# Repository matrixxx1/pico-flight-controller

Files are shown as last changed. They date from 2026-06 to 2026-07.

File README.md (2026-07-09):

# Pico Flight Controller

Raspberry Pi Pico receiver and sensor testbed for a flight-controller-style build.

## Contents

- `main.py` - MicroPython firmware that reads the R8EF PPM signal on Pico `GP15` and drives the PCA9685 outputs through the HW-617 mux.
- `vl53l0x.py` - VL53L0X / UL53LDK distance sensor driver for the remaining side sensors.
- `ControllerTester/` - Vite + Three.js browser dashboard for Web Serial display of receiver and sensor readings.
- `simulator/` - Local browser simulator that generates Pico-shaped serial lines for drift, RC input, and fault testing.
- `QMC5883P.pdf` - Compass sensor reference sheet.
- `RPI_PICO-20260406-v1.28.0.uf2` - MicroPython UF2 used for Pico setup.

## Hardware Used

- Raspberry Pi Pico running MicroPython.
- Radiolink R8EF receiver, powered from the Pico `3V3` rail for bench testing.
- Radiolink transmitter bound to the R8EF.
- Radiolink Gens Ace 7.4V 2S LiPo battery powering the transmitter.
- HW-617 / TCA9548A I2C multiplexer.
- Three VL53L1X time-of-flight distance sensors for bottom, top, and front range sensing.
- Two UL53LDK / VL53L0X time-of-flight distance sensors for left/right side range sensing.
- GY-271 compass module with QMC5883P / HP5883 magnetometer.
- MPU-6050 accelerometer/gyroscope module.
- PCA9685 16-channel 12-bit I2C PWM servo driver.
- Four 60A ESCs for the main motors.
- Four X2807 1300KV brushless motors.
- FEICHAO 8A UBEC regulating the PCA9685 `V+` servo rail to 6V.
- MG995 55g metal-gear servo motors for mount/control-surface outputs.
- Four Hooyu RDS3225 25kg waterproof high-torque digital servos with full metal gears and dual shafts.
- MEUS Racing AUX RC light remote controller switch with LTVystore 5mm 5V prewired LED bulbs.
- Six Ovonic 1000mAh 6S 100C LiPo batteries with XT60 plugs.
- ISDT 60BAC 8A / 200W LiPo balance charger for the main 6S batteries.
- Radiolink CM210 charger for the transmitter battery.
- USB cable from the Pico to the Windows laptop.

## Battery Plan

Current battery inventory:

- `6x` Ovonic 1000mAh 6S 100C LiPo batteries with XT60 plugs.
- `1x` Radiolink Gens Ace 7.4V 2S LiPo battery for the transmitter.
- ISDT 60BAC 8A / 200W LiPo balance charger for the main 6S packs.
- Radiolink CM210 charger for the transmitter battery.

Intended battery assignment:

| Battery | Intended Load | Notes |
|---|---|---|
| 1 | Left front motor / ESC | 6S pack feeds the ESC motor power input. |
| 2 | Right front motor / ESC | 6S pack feeds the ESC motor power input. |
| 3 | Left rear motor / ESC | 6S pack feeds the ESC motor power input. |
| 4 | Right rear motor / ESC | 6S pack feeds the ESC motor power input. |
| 5 | Pico + receiver + HW-617 + sensors | Must go through a regulator/BEC before the Pico; do not connect 6S directly to Pico power pins. |
| 6 | FEICHAO 8A UBEC -> PCA9685 `V+` servo rail | 6S pack feeds the UBEC input; regulated 6V UBEC output feeds PCA9685 `V+`. |

Safety note: a 6S LiPo is `22.2V` nominal and `25.2V` fully charged. The Pico, HW-617, sensors, receiver, PCA9685 logic, and PCA9685 `V+` rail cannot take raw 6S voltage directly. The FEICHAO UBEC sits between the 6S pack and PCA9685 `V+` to cap that rail at 6V.

## Wiring Diagram

Current firmware reads the R8EF PPM stream on `GP15`, then sends flight-control output pulses to the PCA9685 on HW-617 channel 7.

```text
                       USB
Windows laptop <---------------- Raspberry Pi Pico
                                      |
                                      | GP15
                                      v
                              R8EF CH2 signal

Pico 3V3 --------------------+-------- R8EF VCC
                             +-------- HW-617 VCC
                             +-------- Sensor VCC/VIN rails

Pico GND --------------------+-------- R8EF GND
                             +-------- HW-617 GND
                             +-------- Sensor GND rails

Pico GP0 / SDA ---------------------- HW-617 SDA
Pico GP1 / SCL ---------------------- HW-617 SCL

Pico 3V3 ---------------------------- PCA9685 VCC
Pico GND ---------------------------- PCA9685 GND
FEICHAO 8A UBEC 6V OUT + ------------ PCA9685 V+
FEICHAO 8A UBEC GND ----------------- PCA9685 GND

HW-617 CH0: SC0/SCL + SD0/SDA ------- Bottom TOF0 / VL53L1X
HW-617 CH1: SC1/SCL + SD1/SDA ------- Top TOF1 / VL53L1X
HW-617 CH2: SC2/SCL + SD2/SDA ------- Right TOF2 / UL53LDK / VL53L0X
HW-617 CH3: SC3/SCL + SD3/SDA ------- Left TOF3 / UL53LDK / VL53L0X
HW-617 CH4: SC4/SCL + SD4/SDA ------- GY-271 compass
HW-617 CH5: SC5/SCL + SD5/SDA ------- MPU-6050 IMU
HW-617 CH6: SC6/SCL + SD6/SDA ------- Front TOF5 / VL53L1X
HW-617 CH7: SC7/SCL + SD7/SDA ------- PCA9685 PWM servo driver
```

## Wiring Table

| Device | Pin | Connects To | Notes |
|---|---|---|---|
| R8EF | CH2 signal | Pico `GP15` | PPM input for receiver-only firmware. |
| R8EF | VCC / middle pin | Pico `3V3` | The receiver is marked `3-15V`; `3V3` is for bench testing. |
| R8EF | GND / dark pin | Pico `GND` | Must share ground with the Pico. |
| HW-617 / TCA9548A | SDA | Pico `GP0` | Root I2C bus. |
| HW-617 / TCA9548A | SCL | Pico `GP1` | Root I2C bus. |
| HW-617 / TCA9548A | VCC | Pico `3V3` | Keep I2C logic at Pico-safe voltage. |
| HW-617 / TCA9548A | GND | Pico `GND` | Shared ground. |
| PCA9685 | SDA | HW-617 `SD7` | I2C data through mux channel 7. |
| PCA9685 | SCL | HW-617 `SC7` | I2C clock through mux channel 7. |
| PCA9685 | VCC | Pico `3V3` | Logic power; keeps I2C pullups Pico-safe. |
| PCA9685 | GND | Pico `GND` and FEICHAO UBEC GND | Common ground for logic and servo power. |
| PCA9685 | V+ | FEICHAO 8A UBEC regulated 6V output + | Servo/ESC power rail only; do not connect to Pico `3V3` or raw 6S. |
| ESC servo extension leads | Signal + GND only | PCA9685 `CH1`, `CH3`, `CH5`, `CH7` | Disconnect / remove the red wire from each ESC servo extension cable to prevent voltage backfeed into the PCA9685 rail. |
| MG995 55g metal-gear servos | Signal/V+/GND | PCA9685 servo outputs | Servo outputs are powered from the FEICHAO-regulated 6V `V+` rail. |
| Hooyu RDS3225 25kg servos | Signal/V+/GND | Available PCA9685 servo outputs | High-torque digital servos; confirm voltage/current draw before running several from the 8A UBEC at once. |
| Bottom TOF0 / VL53L1X | SDA/SCL | HW-617 `SD0` / `SC0` | Longer-range bottom/altitude distance sensor. |
| Top TOF1 / VL53L1X | SDA/SCL | HW-617 `SD1` / `SC1` | Longer-range top/ceiling distance sensor. |
| Right TOF2 / UL53LDK | SDA/SCL | HW-617 `SD2` / `SC2` | VL53L0X side distance sensor. |
| Left TOF3 / UL53LDK | SDA/SCL | HW-617 `SD3` / `SC3` | VL53L0X side distance sensor. |
| GY-271 | SDA/SCL | HW-617 `SD4` / `SC4` | Compass / magnetometer. |
| MPU-6050 | SDA/SCL | HW-617 `SD5` / `SC5` | Accelerometer/gyro IMU. |
| Front TOF5 / VL53L1X | SDA/SCL | HW-617 `SD6` / `SC6` | Longer-range front distance sensor, connected on mux channel 6. |
| PCA9685 | SDA/SCL | HW-617 `SD7` / `SC7` | PWM servo driver, connected on mux channel 7. |
| All I2C sensors | VCC / VIN | Pico `3V3` rail | Use 3.3V-compatible modules. |
| All I2C sensors | GND | Pico `GND` rail | Shared ground. |

The firmware uses the mux channel to choose the ToF driver because both VL53L0X and VL53L1X modules use the normal `0x29` I2C address. Channels `0`, `1`, and `6` are treated as VL53L1X. Channels `2` and `3` remain VL53L0X.

## PCA9685 Output Labels

The browser viewer labels the 16 PCA9685 outputs as `CH1` through `CH16`. Many PCA9685 boards are silk-screened `0` through `15`; if so, app `CH1` is the board's output `0`, app `CH2` is board output `1`, and so on.

ESC signal leads use servo extension cables into the PCA9685, but the red wire is disconnected/removed on each ESC extension. Only signal and ground are carried through the servo lead so the ESC/BEC side cannot backfeed voltage into the PCA9685 rail.

| App Channel | Output Label |
|---|---|
| CH1 | Left front ESC |
| CH2 | Left Front Mount MG995 servo |
| CH3 | Right front ESC |
| CH4 | Right front Mount MG995 servo |
| CH5 | Left Rear ESC |
| CH6 | Left Rear Mount MG995 servo |
| CH7 | Right Rear ESC |
| CH8 | Right Rear Mount MG995 servo |
| CH9 | Elevator MG995 servo |
| CH10 | Rudder MG995 servo |
| CH11 | Landing Gear MG995 servo |
| CH12 | MEUS Racing AUX RC light switch -> LTVystore 5mm 5V prewired LED bulbs |
| CH13 | Camera Pan MG995 servo |
| CH14 | Camera Tilt MG995 servo |
| CH15 | Spare |
| CH16 | Spare |

## Receiver Control Map

The receiver signal path is:

```text
R8EF CH2 PPM stream -> Pico GP15 -> HW-617 CH7 -> PCA9685 outputs
```

| RC Channel | Transmitter Control | PCA9685 Output |
|---|---|---|
| RC1 | Right stick left/right | Plane/transition rear mount aileron mix on CH6 and CH8; hover side-to-side ESC boost on CH1/CH5 or CH3/CH7, capped inside the 60% joystick ESC authority limit |
| RC2 | Right stick up/down / elevator | Plane elevator on CH9; transition elevator plus slight front ESC boost on CH1/CH3; hover pitch mix on front/rear ESCs and mounts with CH9 elevator centered |
| RC3 | Speed / throttle | CH1, CH3, CH5, CH7 ESC outputs, capped at 60% joystick authority |
| RC4 | Rudder stick | CH10 / board output 9 |
| RC5 | Flight mode / mount-position switch | Low = `flightmode1` / plane, mid = `flightmode2` / transition, high = `flightmode3` / hover |
| RC7 | Control mode switch | Low = RC mode and slow-blink lights; high = PID mode and fast-blink lights |
| RC8 | Trainer / PID gain | Scales throttle above idle, servo/mount travel, stick-driven ESC boosts, PID target bias, and PID correction output from 25% at low to 100% at high |

RC-derived ESC output is capped at `1600us`, which is 60% of the normal `1000us` to `2000us` ESC command range. The remaining 40% is reserved for the Pico's future PID stabilization output, not direct joystick authority. Servo and mount outputs use an expanded `500us` to `2500us` range so full receiver stick travel produces wider servo travel. RC8 acts as a trainer/PID gain: low maps to 25% authority and high maps to full 100% authority. The gain scales throttle above idle, servo deflection from center, mount travel from center, rear mount yaw/aileron mix, hover pitch mix, hover side-to-side ESC boost, PID target bias, and PID correction output; RC5 still selects the flight mode and RC7 selects RC/PID control mode. RC input values use a `6us` deadband to reduce servo jitter from tiny receiver pulse noise. RC5 maps the switch positions to calibrated mount postures: low/plane sends `1580us`, middle/transition sends `1915us`, and high/hover sends `2250us` before RC8 gain scaling. The rear motors are physically set opposite the front motors, so the same mode pulse creates the opposite front/rear posture.

In `flightmode1`, RC2 controls the elevator servo on CH9, RC4 controls the rudder servo, and RC1 controls the rear engine mounts differentially like ailerons. In `flightmode2`, RC2 still controls the elevator and also slightly boosts the front ESCs on CH1 and CH3; RC4 controls the rudder servo and both RC1 and RC4 contribute to rear mount aileron movement on CH6 and CH8. In `flightmode3`, CH9 elevator and CH10 rudder stay centered, RC4 controls rear mount yaw tilt, RC1 commands side-to-side hover movement by slightly increasing the opposing-side ESC pair, and RC2 commands hover pitch: stick up boosts the rear ESCs on CH5 and CH7 while nudging the rear mounts upward, and stick back boosts the front ESCs on CH1 and CH3 while slightly lowering the front mounts. If the receiver signal is missing, ESC outputs go to `1000us`, servos center at `1500us`, RC/PID mode falls back to RC mode, and the flight mode falls back to `flightmode1`.

In RC mode, the remote behaves as the direct command source. In PID mode, the Pico captures the current sensor state when RC7 goes high, then treats remote stick movement as a target-direction bias instead of a replacement for stabilization. Hover mode tries to hold the current world state using level pitch/roll, heading, and bottom-ToF altitude when available; stick commands bias that hold and keep the hover feedforward mixes active, so stick-right still slightly boosts the left front/rear ESCs while PID stabilizes around that movement. Plane mode holds the captured trajectory through attitude and heading corrections while stick commands bias the commanded trajectory. Transition mode blends hover and flight behavior with half-strength corrections. The current sensor stack does not provide GPS or optical-flow X/Y position, so PID mode cannot truly lock horizontal X/Y world position yet; it can only stabilize attitude, heading, and altitude while applying directional movement commands.

The light controller is now driven by mode-change pulses on CH12 instead of direct RC7 passthrough. The controller starts solid when powered; one off/on pulse selects the slow blink pattern, a second off/on pulse selects fast blink, and a third cycles back to solid. RC mode targets slow blink. PID mode targets fast blink.

Rear mount aileron movement is limited before mixing into CH6 and CH8 so roll inputs do not swing the rear motor mounts through their full mechanical range. Plane mode uses 50% rear aileron authority, and transition mode uses 25% rear aileron authority.

In transition and hover, rear mount yaw is capped at the flight-mode mount setting, so turning inputs can pull a rear mount toward flight position but not past it. In transition mode, rudder/yaw input is not added to the aileron differential mix: left rudder pulls the right rear mount toward flight position, and right rudder pulls the left rear mount toward flight position.

Sensor telemetry is lightly smoothed in firmware for steadier display while sitting still. RC channel values are not smoothed before control output, so stick/switch response stays direct.

## R8EF Mode

```text
R8EF CH2 signal -> Pico GP15
R8EF VCC        -> Pico 3V3
R8EF GND        -> Pico GND
```

The R8EF needs SBUS/PPM mode for CH2 to output a combined PPM stream.

- Red LED: PWM mode, each channel is a separate PWM output.
- Blue/purple LED: SBUS/PPM mode, where `CH1` is SBUS and `CH2` is PPM.
- Toggle mode by quick-pressing the receiver `ID SET` button twice within 1 second.

## Browser Viewer

```powershell
cd ControllerTester
npm install
npm run dev -- --port 5173
```

Then open `http://127.0.0.1:5173` in Chrome or Edge and connect to the Pico over Web Serial.

## Simulator

```powershell
cd simulator
.\Start-Simulator.ps1
```

Then open the URL printed by the launcher, starting with `http://127.0.0.1:5174`. The simulator can copy generated serial lines into the `ControllerTester` raw/manual parser, run short RC instruction scripts, read a USB transmitter/game-controller through the browser Gamepad API, and read CH340-style serial adapters through Web Serial.

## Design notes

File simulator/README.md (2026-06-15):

# Pico Setup Simulator

This is a local browser simulator for the Pico flight-controller test setup.

It emits the same one-line text shape as `main.py`, for example:

```text
sensor=QMC5883P / HP5883 x=420 y=0 z=0 xuT=0.42 yuT=0.00 zuT=0.00 heading=0.0 tof0=620 tof1=680 tof2=760 tof3=760 tof6=900 adxl=ok ax=0.000 ay=0.000 az=1.000 pitch=0.0 roll=0.0 rc=ppm rc1=1500 rc2=1500 rc3=1500 rc4=1500 rc5=1000 rc6=1500 rc7=1000 rc8=1500
```

Use it to test:

- Wind drift scenarios.
- RC instruction sequences.
- Low-altitude approach behavior.
- TOF, compass, and stale RC failure modes.
- Manual parser testing in `ControllerTester` by copying the generated serial line.
- USB transmitter/game-controller input through the browser Gamepad API.
- USB serial adapters such as CH340 on `COM4` through Web Serial.

## Launch

From PowerShell:

```powershell
.\Start-Simulator.ps1
```

Or double-click:

```text
Start-Simulator.bat
```

The launcher starts at `http://127.0.0.1:5174`. If that port is busy, it picks the next free port and prints the exact URL.

## USB Transmitter Control

Plug in the transmitter, open the simulator from localhost, then click `Use T8FB`.

Browsers only expose gamepads after user interaction. If the status stays on waiting, move a stick, press a transmitter button, or unplug/replug the USB cable while the simulator is open.

Default mapping:

- Axis 0 -> `rc1` yaw.
- Axis 1 -> `rc2` pitch, inverted.
- Axis 2 -> `rc3` throttle, inverted.
- Axis 3 -> `rc4` roll.

The live USB status shows the raw axes and mapped `rc1..rc4` values so the mapping can be adjusted once we see what the T8FB reports on this laptop.

## Serial Adapter Control

If the transmitter cable appears as `USB-SERIAL CH340 (COM4)`, click `Connect COM4` in the simulator and choose that port from the browser picker.

The simulator tries these input shapes:

- Text lines containing `rc1=... rc2=...`.
- Text lines containing at least four PWM-like values from `900` to `2250`.
- FlySky-style iBUS binary frames.
- SBUS binary frames when baud is set to `100000 SBUS 8E2`.

Start with `115200`. If the status only shows changing raw hex bytes and no channel mapping, try `9600`, `57600`, and `100000 SBUS 8E2`.

## Instruction Script

The script box accepts one instruction per line. Values are receiver PWM microseconds unless noted.

```text
scenario=manual throttle=1550 yaw=1500 pitch=1450 roll=1500 wind=0 hold=1.0
scenario=manual throttle=1580 yaw=1500 pitch=1500 roll=1850 wind=45 hold=1.4
scenario=fault tof=err mag=err rc=stale hold=1.0
```

Useful fields:

- `scenario`: `manual`, `drift`, `rc`, `fault`, or `landing`.
- `throttle`: maps to `rc3`.
- `yaw` or `ch1`: maps to `rc1`.
- `pitch` or `ch2`: maps to `rc2`.
- `roll` or `ch4`: maps to `rc4`.
- `wind`: `-100` to `100`, used for drift.
- `hold`: seconds to hold the instruction.
- `tof=err`, `mag=err`, `rc=stale`: simulate fault modes.

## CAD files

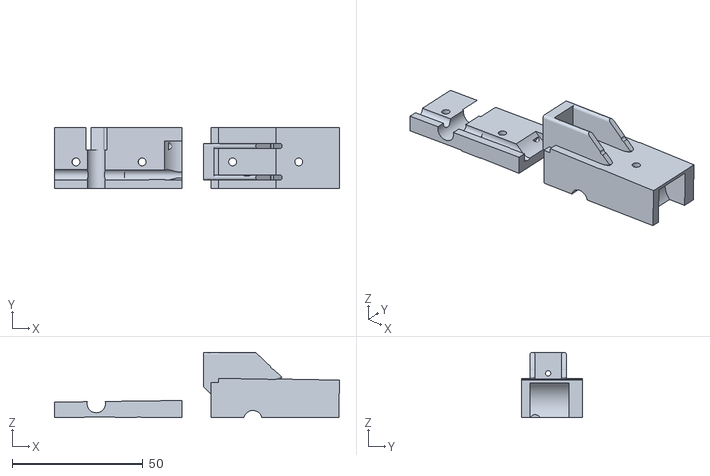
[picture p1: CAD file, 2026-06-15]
3dmodels/Landing_gear_front.stl
108.8 x 23.1 x 24.9

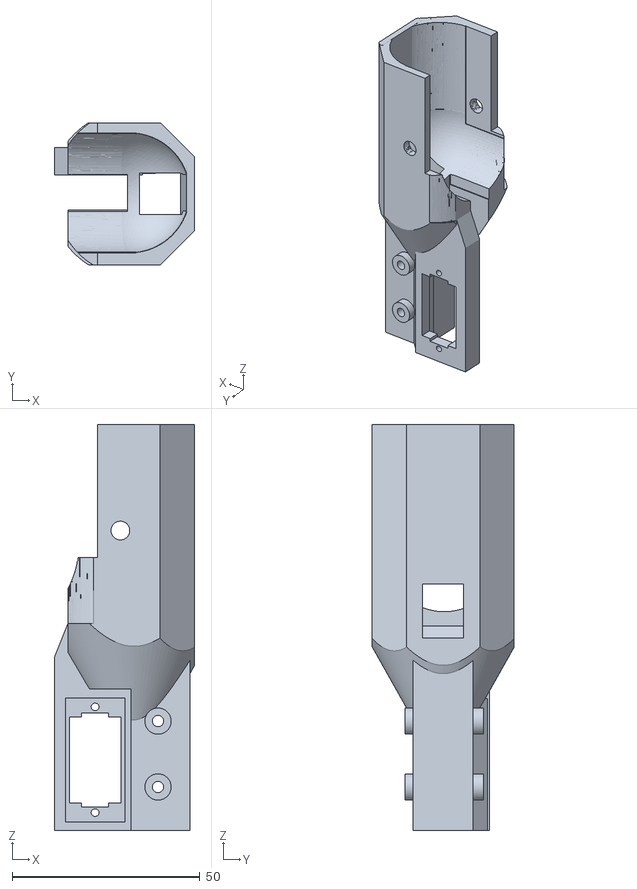
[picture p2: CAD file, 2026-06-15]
3dmodels/Wing_to_EngineMount.stl
37.5 x 38.0 x 108.3

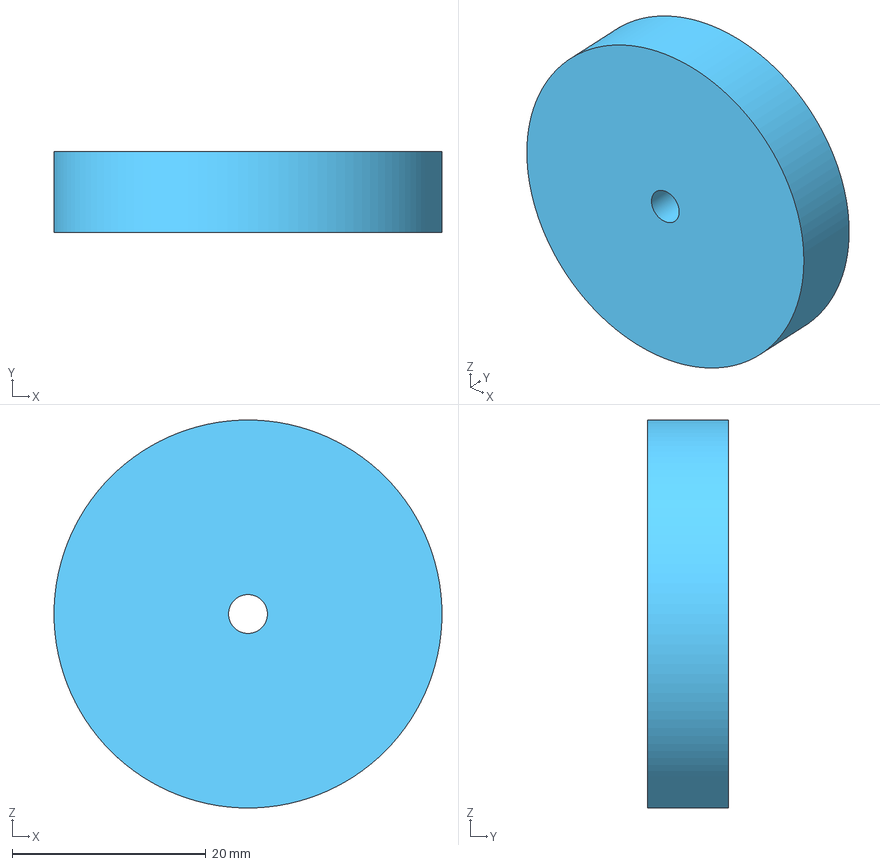
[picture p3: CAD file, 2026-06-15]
3dmodels/Landing_gear_Wheel.3mf
40.0 x 8.37 x 40.0 mm

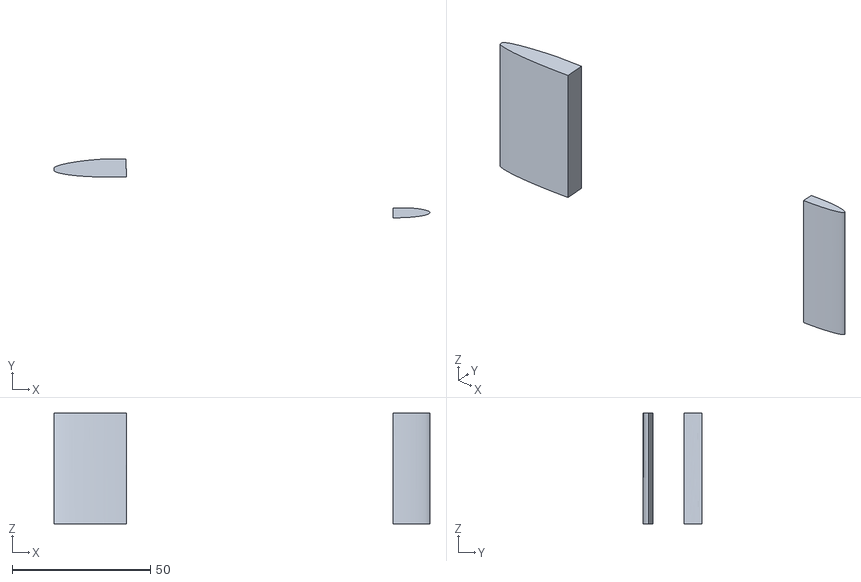
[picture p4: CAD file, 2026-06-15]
3dmodels/Wing_clips.stl
135.9 x 21.2 x 40.0

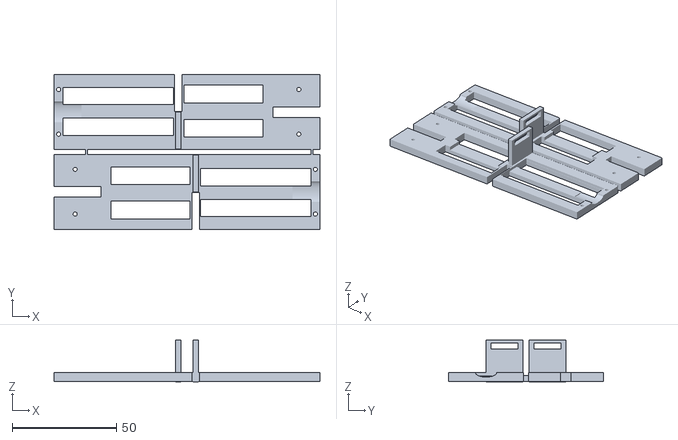
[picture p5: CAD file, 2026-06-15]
3dmodels/pico multiplexor.stl
127.9 x 74.4 x 20.0

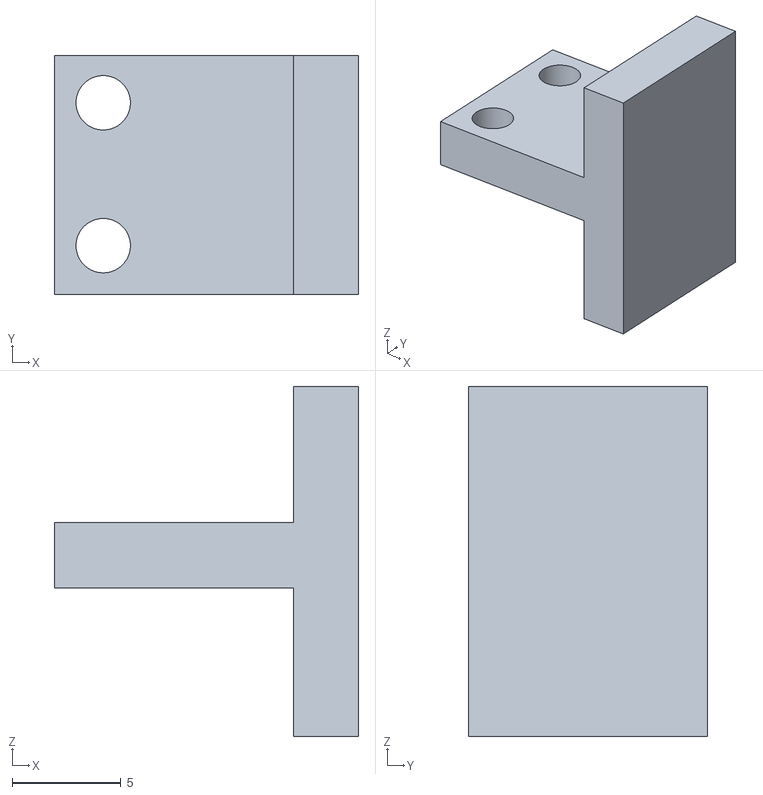
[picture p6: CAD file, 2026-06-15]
3dmodels/vl53LDK.stl
14.0 x 11.0 x 16.1

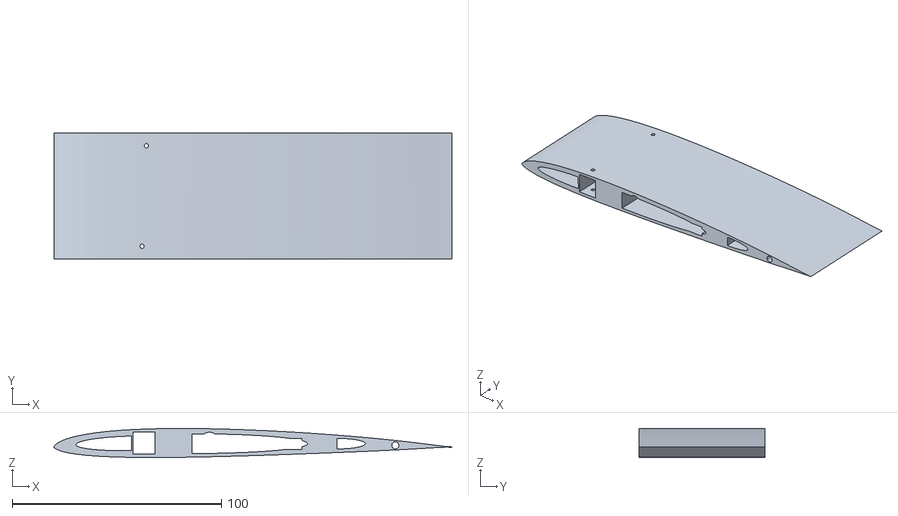
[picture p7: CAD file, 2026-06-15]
3dmodels/shortwings.stl
190.0 x 60.0 x 13.9

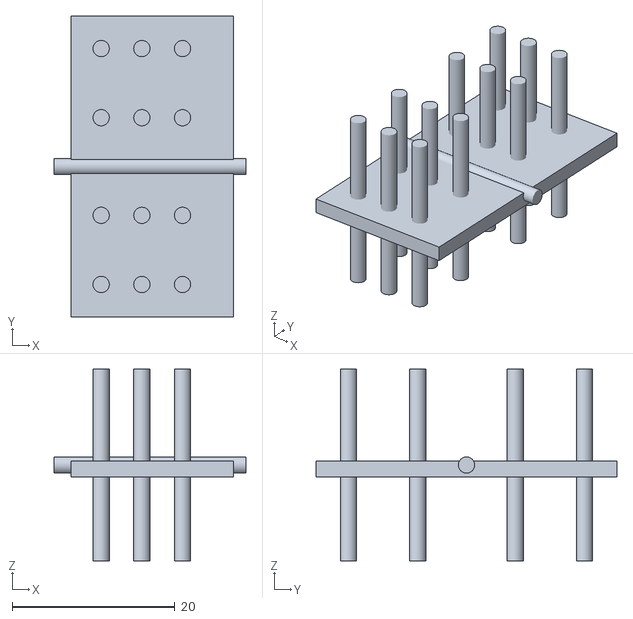
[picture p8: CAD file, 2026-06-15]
3dmodels/hinge.stl
23.6 x 37.0 x 23.6

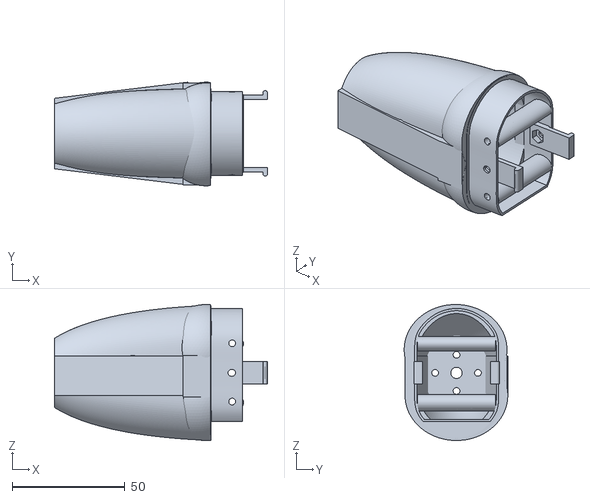
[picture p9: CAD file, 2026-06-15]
3dmodels/Cowl.stl
94.5 x 46.0 x 60.3

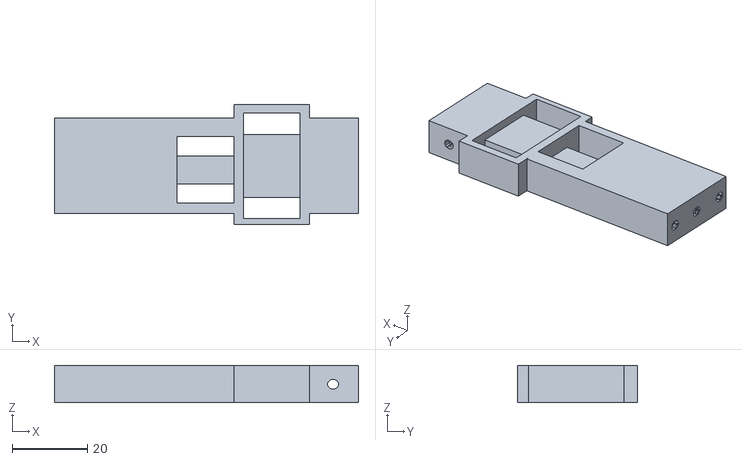
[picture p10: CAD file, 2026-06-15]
3dmodels/Cowl-gyro-plate.stl
80.7 x 31.9 x 9.84

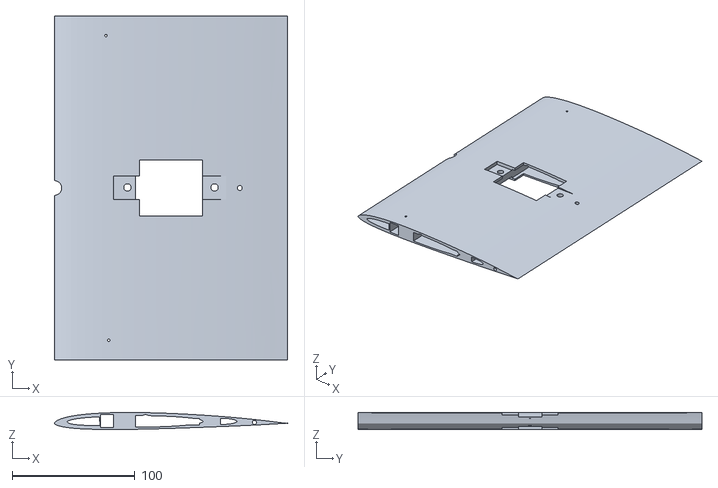
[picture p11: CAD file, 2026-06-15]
3dmodels/Wing_central.stl
190.0 x 280.0 x 13.9

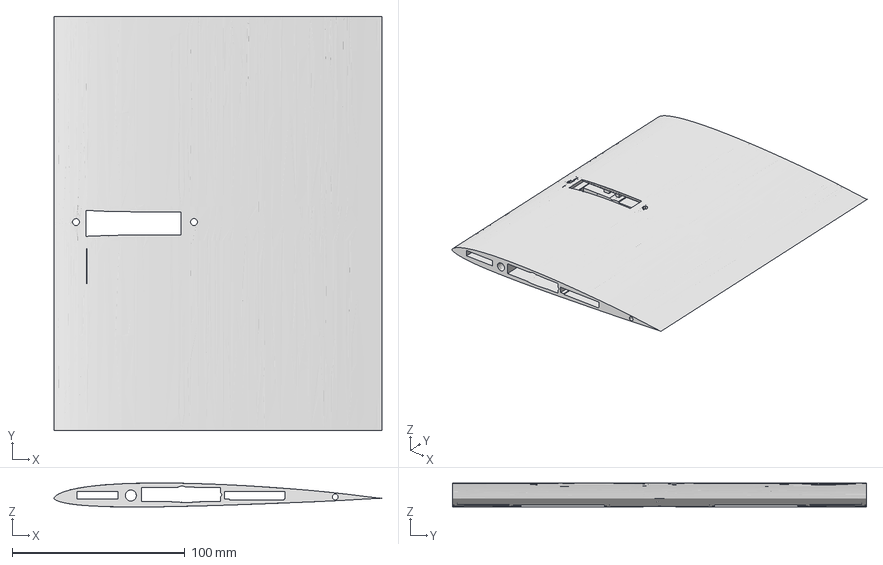
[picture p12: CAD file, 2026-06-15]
3dmodels/Wing_engineMount.3mf
190.0 x 239.9 x 13.8 mm

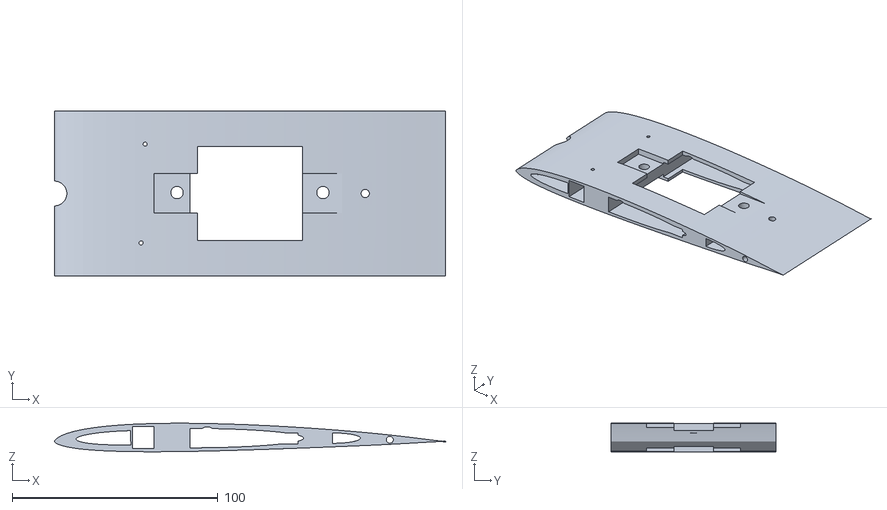
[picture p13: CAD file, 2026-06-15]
3dmodels/short-wing-with-mountl.stl
190.0 x 80.0 x 13.9

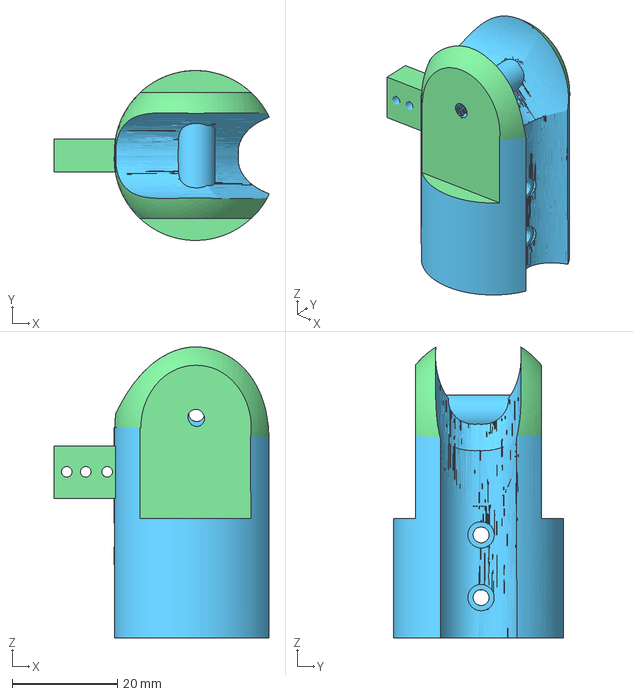
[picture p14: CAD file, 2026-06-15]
3dmodels/EngineMount -Outer.3mf
40.9 x 32.3 x 55.3 mm

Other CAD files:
3dmodels/EngineMount-Inner.stl
3dmodels/NoseCone.stl
3dmodels/rudder.stl
3dmodels/Wing_to_EngineMount-MG995-servo.stl
3dmodels/Elevon.recreated-clean.stl
3dmodels/rear-wheel-mount.stl

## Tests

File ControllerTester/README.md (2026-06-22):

# Pico Controller Tester

Use `Start-ControllerTester.bat` to launch the app.

Do not open `index.html` directly. The app uses browser modules and Web Serial, so it needs to run from `http://127.0.0.1:5173`.

## Pico I2C wiring

Pico shared I2C bus:

```text
Pico 3V3(OUT) -> HW-617 VCC
Pico GND      -> HW-617 GND
Pico GP1      -> HW-617 SCL
Pico GP0      -> HW-617 SDA
```

Sensors through the HW-617:

```text
HW-617 SC0/SD0 -> Bottom TOF0 / VL53L1X SCL/SDA
HW-617 SC1/SD1 -> Top TOF1 / VL53L1X SCL/SDA
HW-617 SC2/SD2 -> Right TOF2 / VL53L0X SCL/SDA
HW-617 SC3/SD3 -> Left TOF3 / VL53L0X SCL/SDA
HW-617 SC4/SD4 -> GY-271 SCL/SDA
HW-617 SC5/SD5 -> MPU-6050 SCL/SDA
HW-617 SC6/SD6 -> Front TOF5 / VL53L1X SCL/SDA
HW-617 SC7/SD7 -> PCA9685 SCL/SDA

HW-617 3V3/GND -> each ToF sensor VIN/GND
HW-617 3V3/GND -> GY-271 VCC/GND
HW-617 3V3/GND -> MPU-6050 VCC/GND
Pico 3V3/GND    -> PCA9685 VCC/GND
External BEC +  -> PCA9685 V+
External BEC GND -> PCA9685 GND
```

The Pico code expects the HW-617/TCA9548A at `0x70`, VL53L1X sensors at normal `0x29` on channels `0`, `1`, and `6`, VL53L0X sensors at normal `0x29` on channels `2` and `3`, the GY-271 on channel `4`, the MPU-6050 at `0x68` or `0x69` on channel `5`, and the PCA9685 at its normal `0x40` address on channel `7`.

## Flight modes

The viewer shows the active flight mode from the Pico serial stream. RC5 low is `flightmode1` / plane mode, RC5 middle is `flightmode2` / transition mode, and RC5 high is `flightmode3` / hover mode. In plane mode, RC4 controls the rudder servo. In transition mode, RC4 controls both the rudder servo and rear mount yaw tilt. In hover mode, RC4 tilts the rear mount pair for yaw while the rudder servo centers.

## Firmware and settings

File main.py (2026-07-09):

from machine import I2C, Pin, disable_irq, enable_irq
from time import sleep, ticks_diff, ticks_us
import math

try:
    from vl53l0x import VL53L0X
except ImportError:
    VL53L0X = None


I2C_BUS = 0
SDA_PIN = 0
SCL_PIN = 1
FREQ = 100_000

QMC5883L_ADDR = 0x0D
HMC5883L_ADDR = 0x1E
QMC5883P_ADDR = 0x2C
QMC5883P_ALT_ADDR = 0x0C
TCA9548A_ADDR = 0x70
PCA9685_ADDR = 0x40
VL53L0X_ADDR = 0x29
ADXL345_ADDR = 0x53
MPU6050_ADDR_LOW = 0x68
MPU6050_ADDR_HIGH = 0x69

TOF_CHANNELS = (0, 1, 2, 3, 6)
VL53L1X_CHANNELS = (0, 1, 6)
MAG_CHANNEL = 4
ADXL_CHANNEL = 5
PCA9685_MUX_CHANNEL = 7

PCA_FREQ_HZ = 50
PCA_OSC_HZ = 25_000_000
PULSE_MIN_US = 500
PULSE_MID_US = 1500
PULSE_MAX_US = 2500
PULSE_THROW_US = PULSE_MAX_US - PULSE_MID_US
ESC_MIN_US = 1000
ESC_MAX_US = 2000
RC_THROTTLE_MAX_US = 1600
RC_INPUT_MIN_US = 1000
RC_INPUT_MAX_US = 2000
RC_INPUT_MID_US = 1500
RC_INPUT_THROW_US = 500
RC_INPUT_DEADBAND_US = 6
LIGHT_OFF_US = 1000
LIGHT_ON_US = 2000
LIGHT_SWITCH_US = 1500
CONTROL_MODE_SWITCH_US = 1500
MOUNT_LOW_THRESHOLD_US = 1300
MOUNT_HIGH_THRESHOLD_US = 1700
MOUNT_FLIGHT_US = 1580
MOUNT_HOVER_US = 2250
MOUNT_TRANSITION_US = (MOUNT_FLIGHT_US + MOUNT_HOVER_US) // 2
RUDDER_LEFT_THRESHOLD_US = 1300
RUDDER_RIGHT_THRESHOLD_US = 1700
RUDDER_DEADBAND_US = 40

FLIGHT_MODE_1 = "flightmode1"
FLIGHT_MODE_2 = "flightmode2"
FLIGHT_MODE_3 = "flightmode3"
FLIGHT_MODE_LOW_THRESHOLD_US = 1300
FLIGHT_MODE_HIGH_THRESHOLD_US = 1700

ESC_OUTPUTS = (0, 2, 4, 6)
LEFT_FRONT_ESC_OUTPUT = 0
RIGHT_FRONT_ESC_OUTPUT = 2
LEFT_REAR_ESC_OUTPUT = 4
RIGHT_REAR_ESC_OUTPUT = 6
LEFT_ESC_OUTPUTS = (0, 4)
RIGHT_ESC_OUTPUTS = (2, 6)
FRONT_ESC_OUTPUTS = (0, 2)
REAR_ESC_OUTPUTS = (4, 6)
MOUNT_OUTPUTS = (1, 3, 5, 7)
FRONT_MOUNT_OUTPUTS = (1, 3)
LEFT_REAR_MOUNT_OUTPUT = 5
RIGHT_REAR_MOUNT_OUTPUT = 7
ELEVATOR_OUTPUT = 8
RUDDER_OUTPUT = 9
LIGHT_OUTPUT = 11
HOVER_SIDE_ESC_BOOST_US = 150
PITCH_ESC_BOOST_US = 150
HOVER_PITCH_MOUNT_ADJUST_US = 150
REAR_AILERON_AUTHORITY_PERCENT = 50
TRANSITION_REAR_AILERON_AUTHORITY_PERCENT = 25
TRAINER_GAIN_MIN_PERCENT = 25
TRAINER_GAIN_MAX_PERCENT = 100
CONTROL_MODE_RC = "rc"
CONTROL_MODE_PID = "pid"
LIGHT_MODE_SOLID = 0
LIGHT_MODE_SLOW_BLINK = 1
LIGHT_MODE_FAST_BLINK = 2
LIGHT_PULSE_INTERVAL_US = 250_000
PID_OUTPUT_LIMIT_US = 80
PID_LEVEL_KP = 5.0
PID_LEVEL_KI = 0.02
PID_LEVEL_KD = 0.8
PID_HEADING_KP = 1.4
PID_HEADING_KI = 0.01
PID_HEADING_KD = 0.35
PID_ALTITUDE_KP = 0.18
PID_ALTITUDE_KI = 0.005
PID_ALTITUDE_KD = 0.08
PID_COMMAND_PITCH_DEG = 8.0
PID_COMMAND_ROLL_DEG = 8.0
PID_COMMAND_YAW_DEG = 4.0
PID_COMMAND_ALTITUDE_MM = 20.0

PPM_PIN = 15
RC_CHANNELS = 8
PPM_SYNC_US = 3000
PPM_MIN_US = 750
PPM_MAX_US = 2250
PPM_STALE_US = 250_000

REPORT_INTERVAL_S = 0.10
SENSOR_RETRY_US = 5_000_000
MAG_SMOOTH_ALPHA = 0.18
IMU_SMOOTH_ALPHA = 0.22
TOF_SMOOTH_ALPHA = 0.25

VL53L1X_DEFAULT_CONFIGURATION = bytes([
    0x00, 0x00, 0x00, 0x01, 0x02, 0x00, 0x02, 0x08,
    0x00, 0x08, 0x10, 0x01, 0x01, 0x00, 0x00, 0x00,
    0x00, 0xFF, 0x00, 0x0F, 0x00, 0x00, 0x00, 0x00,
    0x00, 0x20, 0x0B, 0x00, 0x00, 0x02, 0x0A, 0x21,
    0x00, 0x00, 0x05, 0x00, 0x00, 0x00, 0x00, 0xC8,
    0x00, 0x00, 0x38, 0xFF, 0x01, 0x00, 0x08, 0x00,
    0x00, 0x01, 0xDB, 0x0F, 0x01, 0xF1, 0x0D, 0x01,
    0x68, 0x00, 0x80, 0x08, 0xB8, 0x00, 0x00, 0x00,
    0x00, 0x0F, 0x89, 0x00, 0x00, 0x00, 0x00, 0x00,
    0x00, 0x00, 0x01, 0x0F, 0x0D, 0x0E, 0x0E, 0x00,
    0x00, 0x02, 0xC7, 0xFF, 0x9B, 0x00, 0x00, 0x00,
    0x01, 0x01, 0x40,
])


def twos_complement(value, bits=16):
    if value & (1 << (bits - 1)):
        value -= 1 << bits
    return value


def heading_degrees(x, y):
    heading = math.degrees(math.atan2(y, x))
    if heading < 0:
        heading += 360
    return heading


def normalize_degrees(degrees):
    while degrees > 180:
        degrees -= 360
    while degrees < -180:
        degrees += 360
    return degrees


class ExpSmoother:
    def __init__(self, alpha):
        self.alpha = alpha
        self.values = {}

    def reset(self, key=None):
        if key is None:
            self.values = {}
        elif key in self.values:
            del self.values[key]

    def update(self, key, value):
        previous = self.values.get(key)
        if previous is None:
            self.values[key] = value
            return value
        smoothed = previous + self.alpha * (value - previous)
        self.values[key] = smoothed
        return smoothed


def smooth_vector(smoother, prefix, values):
    return tuple(smoother.update("{}{}".format(prefix, index), value) for index, value in enumerate(values))


class PPMReceiver:
    def __init__(self, pin_number, channel_count=RC_CHANNELS):
        self.pin = Pin(pin_number, Pin.IN, Pin.PULL_DOWN)
        self.channel_count = channel_count
        self.channels = [None] * channel_count
        self.index = 0
        self.last_edge_us = ticks_us()
        self.last_frame_us = 0
        self.pin.irq(trigger=Pin.IRQ_RISING, handler=self._on_rising_edge)

    def _on_rising_edge(self, pin):
        now = ticks_us()
        width = ticks_diff(now, self.last_edge_us)
        self.last_edge_us = now

        if width > PPM_SYNC_US:
            self.index = 0
            self.last_frame_us = now
            return

        if PPM_MIN_US <= width <= PPM_MAX_US and self.index < self.channel_count:
            self.channels[self.index] = width
            self.index += 1

    def read(self):
        irq_state = disable_irq()
        values = self.channels[:]
        last_frame_us = self.last_frame_us
        enable_irq(irq_state)
        if last_frame_us == 0 or ticks_diff(ticks_us(), last_frame_us) > PPM_STALE_US:
            return [None] * self.channel_count
        return values


class RCInputFilter:
    def __init__(self, channel_count=RC_CHANNELS, deadband_us=RC_INPUT_DEADBAND_US):
        self.deadband_us = deadband_us
        self.values = [None] * channel_count

    def update(self, channels):
        filtered = []
        for index, value in enumerate(channels):
            previous = self.values[index]
            if value is None:
                self.values[index] = None
                filtered.append(None)
            elif previous is None or abs(value - previous) > self.deadband_us:
                self.values[index] = value
                filtered.append(value)
            else:
                filtered.append(previous)
        return filtered


class LightPatternController:
    def __init__(self):
        self.current_mode = LIGHT_MODE_SOLID
        self.target_mode = None
        self.remaining_steps = 0
        self.output_on = True
        self.last_step_us = ticks_us()

    def set_target(self, target_mode):
        target_mode = int(clamp(target_mode, LIGHT_MODE_SOLID, LIGHT_MODE_FAST_BLINK))
        if self.target_mode == target_mode and self.remaining_steps > 0:
            return
        if self.current_mode == target_mode:
            self.target_mode = target_mode
            return
        cycles = (target_mode - self.current_mode) % 3
        self.remaining_steps = cycles * 2
        self.target_mode = target_mode
        self.last_step_us = ticks_us() - LIGHT_PULSE_INTERVAL_US

    def update(self):
        if self.remaining_steps > 0 and ticks_diff(ticks_us(), self.last_step_us) >= LIGHT_PULSE_INTERVAL_US:
            self.output_on = not self.output_on
            self.remaining_steps -= 1
            self.last_step_us = ticks_us()
            if self.remaining_steps == 0:
                self.output_on = True
                self.current_mode = self.target_mode
        return LIGHT_ON_US if self.output_on else LIGHT_OFF_US

    def label(self):
        if self.current_mode == LIGHT_MODE_FAST_BLINK:
            return "fast"
        if self.current_mode == LIGHT_MODE_SLOW_BLINK:
            return "slow"
        return "solid"


class PIDAxis:
    def __init__(self, kp, ki, kd, output_limit):
        self.kp = kp
        self.ki = ki
        self.kd = kd
        self.output_limit = output_limit
        self.integral = 0.0
        self.previous_error = 0.0
        self.last_us = None

    def reset(self):
        self.integral = 0.0
        self.previous_error = 0.0
        self.last_us = None

    def update(self, error):
        now = ticks_us()
        if self.last_us is None:
            dt = REPORT_INTERVAL_S
        else:
            dt = max(0.001, ticks_diff(now, self.last_us) / 1_000_000)
        self.last_us = now
        self.integral = clamp(self.integral + error * dt, -self.output_limit, self.output_limit)
        derivative = (error - self.previous_error) / dt
        self.previous_error = error
        output = self.kp * error + self.ki * self.integral + self.kd * derivative
        return int(clamp(output, -self.output_limit, self.output_limit))


class FlightPIDController:
    def __init__(self):
        self.active = False
        self.flight_mode = None
        self.target_pitch = 0.0
        self.target_roll = 0.0
        self.target_heading = None
        self.target_altitude = None
        self.pitch = PIDAxis(PID_LEVEL_KP, PID_LEVEL_KI, PID_LEVEL_KD, PID_OUTPUT_LIMIT_US)
        self.roll = PIDAxis(PID_LEVEL_KP, PID_LEVEL_KI, PID_LEVEL_KD, PID_OUTPUT_LIMIT_US)
        self.heading = PIDAxis(PID_HEADING_KP, PID_HEADING_KI, PID_HEADING_KD, PID_OUTPUT_LIMIT_US)
        self.altitude = PIDAxis(PID_ALTITUDE_KP, PID_ALTITUDE_KI, PID_ALTITUDE_KD, PID_OUTPUT_LIMIT_US)

    def reset_axes(self):
        self.pitch.reset()
        self.roll.reset()
        self.heading.reset()
        self.altitude.reset()

    def set_mode(self, enabled, flight_mode, sensor_state):
        if not enabled:
            if self.active:
                self.reset_axes()
            self.active = False
            self.flight_mode = None
            return
        if not self.active or self.flight_mode != flight_mode:
            self.active = True
            self.flight_mode = flight_mode
            self.reset_axes()
            pitch = sensor_state.get("pitch")
            roll = sensor_state.get("roll")
            heading = sensor_state.get("heading")
            altitude = sensor_state.get("altitude")
            if flight_mode == FLIGHT_MODE_3:
                self.target_pitch = 0.0
                self.target_roll = 0.0
            else:
                self.target_pitch = pitch if pitch is not None else 0.0
                self.target_roll = roll if roll is not None else 0.0
            self.target_heading = heading
            self.target_altitude = altitude

    def corrections(self, sensor_state, flight_mode, command=None, gain_percent=TRAINER_GAIN_MAX_PERCENT):
        if not self.active:
            return {"pitch": 0, "roll": 0, "yaw": 0, "altitude": 0, "status": "off"}
        command = command or {"pitch": 0, "roll": 0, "yaw": 0, "altitude": 0}
        mode_mix = 1.0
        if flight_mode == FLIGHT_MODE_2:
            mode_mix = 0.5
        gain_mix = clamp(gain_percent, TRAINER_GAIN_MIN_PERCENT, TRAINER_GAIN_MAX_PERCENT) / 100
        pitch = sensor_state.get("pitch")
        roll = sensor_state.get("roll")
        heading = sensor_state.get("heading")
        altitude = sensor_state.get("altitude")
        commanded_pitch = self.target_pitch + command.get("pitch", 0)
        commanded_roll = self.target_roll + command.get("roll", 0)
        pitch_out = self.pitch.update(commanded_pitch - pitch) if pitch is not None else 0
        roll_out = self.roll.update(commanded_roll - roll) if roll is not None else 0
        yaw_out = 0
        if heading is not None and self.target_heading is not None:
            yaw_error = normalize_degrees((self.target_heading + command.get("yaw", 0)) - heading)
            yaw_out = self.heading.update(yaw_error)
        alt_out = 0
        if altitude is not None and self.target_altitude is not None and flight_mode != FLIGHT_MODE_1:
            alt_out = self.altitude.update((self.target_altitude + command.get("altitude", 0)) - altitude)
        status = "hold"
        if pitch is None or roll is None:
            status = "noimu"
        elif heading is None:
            status = "noheading"
        return {
            "pitch": int(pitch_out * mode_mix * gain_mix),
            "roll": int(roll_out * mode_mix * gain_mix),
            "yaw": int(yaw_out * mode_mix * gain_mix),
            "altitude": int(alt_out * mode_mix * gain_mix),
            "status": status,
        }


class QMC5883L:
    name = "QMC5883L"

    def __init__(self, i2c):
        self.i2c = i2c
        self.addr = QMC5883L_ADDR
        self.i2c.writeto_mem(self.addr, 0x0B, bytes([0x01]))
        self.i2c.writeto_mem(self.addr, 0x09, bytes([0x1D]))

    def read(self):
        data = self.i2c.readfrom_mem(self.addr, 0x00, 6)
        x = twos_complement(data[1] << 8 | data[0])
        y = twos_complement(data[3] << 8 | data[2])
        z = twos_complement(data[5] << 8 | data[4])
        return x, y, z


class QMC5883P:
    base_name = "QMC5883P / HP5883"

    def __init__(self, i2c, address=QMC5883P_ADDR):
        self.i2c = i2c
        self.addr = address
        self.name = "{} @0x{:02X}".format(self.base_name, self.addr)
        chip_id = self.i2c.readfrom_mem(self.addr, 0x00, 1)[0]
        if chip_id != 0x80:
            raise RuntimeError("QMC5883P chip ID was 0x{:02x}".format(chip_id))
        self.i2c.writeto_mem(self.addr, 0x0D, bytes([0x40]))
        sleep(0.01)
        self.i2c.writeto_mem(self.addr, 0x29, bytes([0x06]))
        sleep(0.01)
        self.i2c.writeto_mem(self.addr, 0x0A, bytes([0xCF]))
        sleep(0.01)
        self.i2c.writeto_mem(self.addr, 0x0B, bytes([0x00]))
        sleep(0.01)

    def read(self):
        for _ in range(100):
            status = self.i2c.readfrom_mem(self.addr, 0x09, 1)[0]
            if status & 0x01:
                break
            sleep(0.001)
        data = self.i2c.readfrom_mem(self.addr, 0x01, 6)
        x = twos_complement(data[1] << 8 | data[0])
        y = twos_complement(data[3] << 8 | data[2])
        z = twos_complement(data[5] << 8 | data[4])
        return x, y, z

    def raw_to_microtesla(self, value):
        return value / 1000.0


class HMC5883L:
    name = "HMC5883L"

    def __init__(self, i2c):
        self.i2c = i2c
        self.addr = HMC5883L_ADDR
        self.i2c.writeto_mem(self.addr, 0x00, bytes([0x70]))
        self.i2c.writeto_mem(self.addr, 0x01, bytes([0x20]))
        self.i2c.writeto_mem(self.addr, 0x02, bytes([0x00]))

    def read(self):
        data = self.i2c.readfrom_mem(self.addr, 0x03, 6)
        x = twos_complement(data[0] << 8 | data[1])
        z = twos_complement(data[2] << 8 | data[3])
        y = twos_complement(data[4] << 8 | data[5])
        return x, y, z


class TCA9548A:
    def __init__(self, i2c, address=TCA9548A_ADDR):
        self.i2c = i2c
        self.address = address

    def select(self, channel):
        self.i2c.writeto(self.address, bytes([1 << channel]))
        sleep(0.002)

    def disable(self):
        self.i2c.writeto(self.address, b"\x00")
        sleep(0.001)

    def safe_disable(self):
        try:
            self.disable()
        except OSError as exc:
            print("TCA disable failed:", exc)


class PCA9685:
    MODE1 = 0x00
    PRESCALE = 0xFE
    LED0_ON_L = 0x06

    def __init__(self, mux, channel=PCA9685_MUX_CHANNEL, address=PCA9685_ADDR, freq=PCA_FREQ_HZ):
        self.mux = mux
        self.channel = channel
        self.i2c = mux.i2c
        self.address = address
        self.mux.select(channel)
        self.i2c.writeto_mem(self.address, self.MODE1, bytes([0x00]))
        sleep(0.01)
        self.set_pwm_freq(freq)

    def _write(self, register, value):
        self.mux.select(self.channel)
        self.i2c.writeto_mem(self.address, register, bytes([value & 0xFF]))

    def _read(self, register):
        self.mux.select(self.channel)
        return self.i2c.readfrom_mem(self.address, register, 1)[0]

    def set_pwm_freq(self, freq):
        prescale = int((PCA_OSC_HZ / (4096 * freq)) - 1 + 0.5)
        old_mode = self._read(self.MODE1)
        sleep_mode = (old_mode & 0x7F) | 0x10
        self._write(self.MODE1, sleep_mode)
        self._write(self.PRESCALE, prescale)
        self._write(self.MODE1, old_mode)
        sleep(0.005)
        self._write(self.MODE1, old_mode | 0xA1)

    def set_pwm(self, output, on, off):
        self.mux.select(self.channel)
        register = self.LED0_ON_L + 4 * output
        data = bytes([on & 0xFF, on >> 8, off & 0xFF, off >> 8])
        self.i2c.writeto_mem(self.address, register, data)

    def set_pulse_us(self, output, pulse_us):
        pulse_us = clamp(pulse_us, PULSE_MIN_US, PULSE_MAX_US)
        ticks = int(pulse_us * PCA_FREQ_HZ * 4096 / 1_000_000)
        self.set_pwm(output, 0, ticks)

    def set_on_off(self, output, is_on):
        if is_on:
            self.set_pwm(output, 0x1000, 0)
        else:
            self.set_pwm(output, 0, 0x1000)

    def neutralize(self):
        for output in ESC_OUTPUTS:
            self.set_pulse_us(output, ESC_MIN_US)
        for output in MOUNT_OUTPUTS:
            self.set_pulse_us(output, PULSE_MID_US)
        self.set_pulse_us(ELEVATOR_OUTPUT, PULSE_MID_US)
        self.set_pulse_us(RUDDER_OUTPUT, PULSE_MID_US)
        self.set_pulse_us(LIGHT_OUTPUT, LIGHT_OFF_US)


class MuxedVL53L0X:
    def __init__(self, mux, channel):
        if VL53L0X is None:
            raise RuntimeError("vl53l0x.py is missing from the Pico")
        self.mux = mux
        self.channel = channel
        self.name = "VL53L0X"
        self.mux.select(channel)
        self.sensor = VL53L0X(self.mux.i2c, address=VL53L0X_ADDR, io_timeout_ms=250)

    def read_mm(self):
        self.mux.select(self.channel)
        return self.sensor.range


class MuxedVL53L1X:
    def __init__(self, mux, channel, address=VL53L0X_ADDR):
        self.mux = mux
        self.channel = channel
        self.address = address
        self.name = "VL53L1X"
        self.mux.select(channel)
        self.reset()
        sleep(0.001)
        if self.read_reg16(0x010F) != 0xEACC:
            raise RuntimeError("VL53L1X model ID mismatch")
        self.mux.i2c.writeto_mem(
            self.address,
            0x002D,
            VL53L1X_DEFAULT_CONFIGURATION,
            addrsize=16,
        )
        self.write_reg16(0x001E, self.read_reg16(0x0022) * 4)
        sleep(0.2)

    def write_reg(self, register, value):
        self.mux.select(self.channel)
        self.mux.i2c.writeto_mem(self.address, register, bytes([value & 0xFF]), addrsize=16)

    def write_reg16(self, register, value):
        self.mux.select(self.channel)
        self.mux.i2c.writeto_mem(
            self.address,
            register,
            bytes([(value >> 8) & 0xFF, value & 0xFF]),
            addrsize=16,
        )

    def read_reg16(self, register):
        self.mux.select(self.channel)
        data = self.mux.i2c.readfrom_mem(self.address, register, 2, addrsize=16)
        return (data[0] << 8) | data[1]

    def reset(self):
        self.write_reg(0x0000, 0x00)
        sleep(0.1)
        self.write_reg(0x0000, 0x01)
        sleep(0.1)

    def read_mm(self):
        self.mux.select(self.channel)
        data = self.mux.i2c.readfrom_mem(self.address, 0x0089, 17, addrsize=16)
        value = (data[13] << 8) | data[14]
        self.write_reg(0x0086, 0x01)
        return value


class MuxedMagnetometer:
    def __init__(self, mux, channel, sensor):
        self.mux = mux
        self.channel = channel
        self.sensor = sensor
        self.name = sensor.name

    def read(self):
        self.mux.select(self.channel)
        return self.sensor.read()

    def raw_to_microtesla(self, value):
        return self.sensor.raw_to_microtesla(value)


class ADXL345:
    def __init__(self, i2c, address=ADXL345_ADDR):
        self.i2c = i2c
        self.address = address
        device_id = self.i2c.readfrom_mem(self.address, 0x00, 1)[0]
        if device_id != 0xE5:
            raise RuntimeError("ADXL345 device ID was 0x{:02x}".format(device_id))
        self.i2c.writeto_mem(self.address, 0x31, bytes([0x08]))
        self.i2c.writeto_mem(self.address, 0x2C, bytes([0x0A]))
        self.i2c.writeto_mem(self.address, 0x2D, bytes([0x08]))
        sleep(0.02)

    def read_raw(self):
        data = self.i2c.readfrom_mem(self.address, 0x32, 6)
        x = twos_complement(data[1] << 8 | data[0])
        y = twos_complement(data[3] << 8 | data[2])
        z = twos_complement(data[5] << 8 | data[4])
        return x, y, z

    def read_g(self):
        x, y, z = self.read_raw()
        return x * 0.0039, y * 0.0039, z * 0.0039


class MuxedADXL345:
    def __init__(self, mux, channel):
        self.mux = mux
        self.channel = channel
        self.mux.select(channel)
        self.sensor = ADXL345(self.mux.i2c)

    def read(self):
        self.mux.select(self.channel)
        return self.sensor.read_g()


class MPU6050:
    name = "MPU-6050"

    def __init__(self, i2c, address):
        self.i2c = i2c
        self.address = address
        who_am_i = self.i2c.readfrom_mem(self.address, 0x75, 1)[0]
        if who_am_i not in (0x68, 0x69):
            raise RuntimeError("MPU-6050 WHO_AM_I was 0x{:02x}".format(who_am_i))
        self.i2c.writeto_mem(self.address, 0x6B, bytes([0x00]))
        sleep(0.05)
        self.i2c.writeto_mem(self.address, 0x1A, bytes([0x03]))
        self.i2c.writeto_mem(self.address, 0x1B, bytes([0x00]))
        self.i2c.writeto_mem(self.address, 0x1C, bytes([0x00]))
        sleep(0.02)

    def read_g(self):
        data = self.i2c.readfrom_mem(self.address, 0x3B, 6)
        x = twos_complement(data[0] << 8 | data[1])
        y = twos_complement(data[2] << 8 | data[3])
        z = twos_complement(data[4] << 8 | data[5])
        return x / 16384.0, y / 16384.0, z / 16384.0
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

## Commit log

2026-06-14 Initial Pico flight controller workspace
2026-06-14 Document hardware and wiring
2026-06-14 Restore full sensor firmware
2026-06-15 Swap mapped ADXL pitch and roll axes
2026-06-15 Show I2C sensor fault status
2026-06-15 Fix RC display when TOF sensors are missing
2026-06-15 Add PCA9685 wiring and output map
2026-06-15 Add simulator and 3D model assets
    [Cowl-gyro-plate.stl, Cowl.stl, Elevon.recreated-clean.stl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]
2026-06-17 Add muxed servo output control
2026-07-09 Add PID assist and RC gain controls
